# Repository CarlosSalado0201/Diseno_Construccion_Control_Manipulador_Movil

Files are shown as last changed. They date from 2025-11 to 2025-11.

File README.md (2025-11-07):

# 🤖 Diseño, Construcción y Control de un Manipulador Móvil

**Autor:** Carlos Alberto Salado Chávez  
**Institución:** Universidad Tecnológica de la Mixteca – Ingeniería en Mecatrónica  
**Directores:** Dr. Oscar David Ramírez Cárdenas | Dr. Miguel Alberto Domínguez Gurría  
**Fecha:** Noviembre de 2025  

---

## 📘 Descripción general

Este repositorio contiene todo el material correspondiente al proyecto de tesis  
**“Diseño, construcción y control de un manipulador móvil”**, desarrollado en la Universidad Tecnológica de la Mixteca.

El proyecto abarca desde el modelado CAD y la simulación en CoppeliaSim,  
hasta la construcción física del robot y su control cinemático implementado en Arduino.  

El manipulador móvil diseñado utiliza **ruedas omnidireccionales** y un **brazo robótico de 5 grados de libertad**,  
controlado mediante un modelo cinemático combinado que permite posicionar el efector final en el espacio tridimensional.

---

## 🎯 Objetivo general

Diseñar y construir un robot manipulador móvil con ruedas omnidireccionales,  
desarrollando un modelo de control cinemático combinado que coordine los movimientos  
del sistema móvil y del manipulador para alcanzar puntos específicos en el espacio tridimensional.

---

## ⚙️ Estructura del repositorio

```bash
DISENO_CONSTRUCCION_Y_CONTROL_DE_UN_MANIPULADOR_MOVIL/
│
├── CAD_Modelo/                  # Modelado 3D en formato STEP
│   ├── Dibujos_Tecnicos/        # Planos técnicos en PDF
│   └── README_CAD.txt
│
├── Codigo_Arduino/              # Programación del sistema en Arduino
│   ├── Control_Cinematico_Robot_Manipulador_CAOS/
│   ├── mamalon5/
│   └── Lectura_Grafica_monitor_Serial.py
│
├── CoppeliaSim/                 # Simulación del robot en entorno virtual
│
├── Documento/                   # Tesis completa en formato PDF
│
├── PCB_Eagle/                   # Diseño electrónico de la PCB y librerías
│
├── Resultados_Matlab/           # Datos experimentales y scripts de análisis
│
├── VIDEOS/                      # Pruebas experimentales y simulaciones
│
└── README.md                    # Este archivo

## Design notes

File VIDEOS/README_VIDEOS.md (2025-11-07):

# 🎥 VIDEOS – Pruebas y Simulaciones del Manipulador Móvil

Este directorio contiene los **videos experimentales y de simulación** correspondientes a la tesis:

> **“Diseño, construcción y control de un manipulador móvil”**  
> Universidad Tecnológica de la Mixteca  
> Autor: *Carlos Alberto Salado Chávez*  
> Noviembre de 2025

---

## 🧠 Descripción general

Los videos documentan el funcionamiento tanto **virtual (simulado)** como **físico (prototipo real)**  
del robot manipulador móvil omnidireccional desarrollado en el proyecto.  
En cada grabación se muestran distintos aspectos del control cinemático y la coordinación entre la base móvil y el brazo.

---

## 📂 Contenido

| Archivo | Descripción |
|---|---|
| `Primera_simulacion.mp4` | Primera simulación del manipulador móvil en CoppeliaSim (movimiento combinado). |
| `Segunda_simulacion.mp4` | Prueba de control de orientación y posicionamiento del manipulador en simulación. |
| `Tercera_simulacion.mp4` | Simulación completa de seguimiento de trayectoria y orientación del efector final. |
| `Simulacion_manipulador.mp4` | Simulación individual del brazo robótico (cinemática directa e inversa). |
| `Simulacion_Movil.mp4` | Simulación individual del robot móvil omnidireccional. |
| `Primera_prueba.mp4` | Prueba experimental real del robot ensamblado, validando control básico. |
| `Segunda_prueba.mp4` | Prueba de posicionamiento y coordinación entre base móvil y manipulador. |
| `Tercera_prueba.mp4` | Prueba final del sistema completo en entorno controlado. |
| `Representacion_Valores_leidos.mp4` | Visualización de datos de sensores en tiempo real. |
| `Representacion_Valores_leidos_prueba2.mp4` | Segunda prueba de lectura y graficación de variables. |
| `Representacion_Valores_leidos_prueba3.mp4` | Tercera prueba de lectura y graficación de variables. |

---

## ⚙️ Recomendaciones

- Los videos están en formato **.mp4** y pueden abrirse con cualquier reproductor moderno (VLC, Windows Media Player, etc.).  
- Se recomienda **no subirlos directamente a GitHub** si superan los 25 MB;  
  en su lugar, puedes subirlos a **Google Drive, YouTube o GitHub Releases**,  
  y dejar aquí los enlaces de descarga o visualización.

Ejemplo:

```markdown
🔗 [Ver Primera simulación en Google Drive](https://drive.google.com/...)

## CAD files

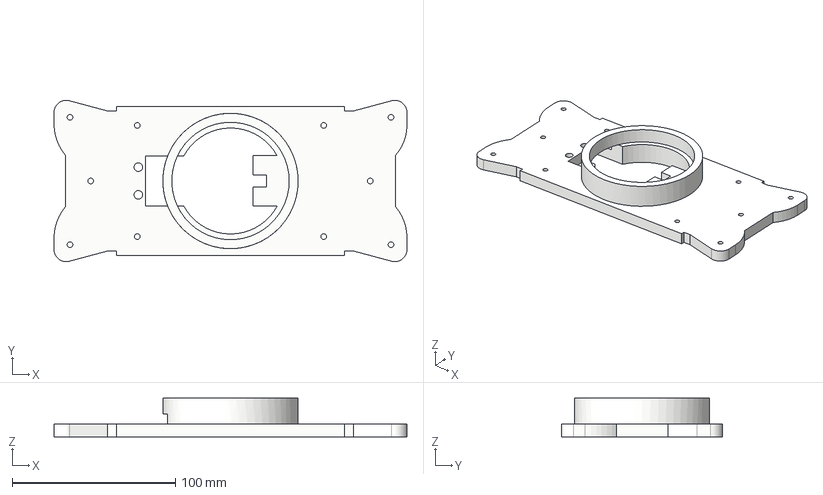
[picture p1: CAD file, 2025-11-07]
CAD_Modelo/tapaa_a_servo_2 v1.step
216.5 x 98.9 x 23.7 mm

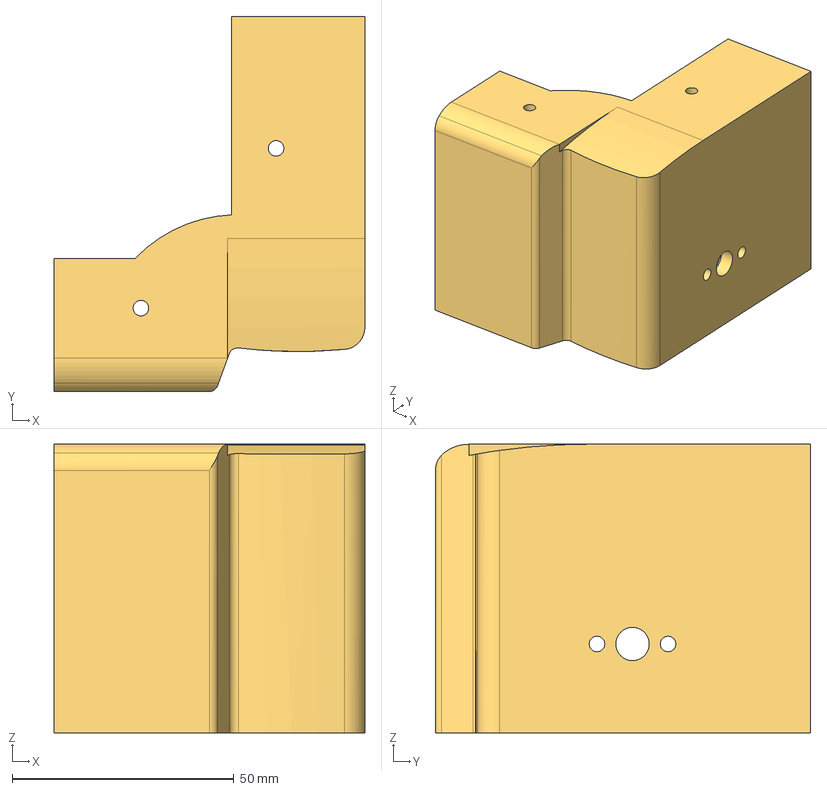
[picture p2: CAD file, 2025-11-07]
CAD_Modelo/Youbot_Componente1_Pieza4 v1.step
70.0 x 84.5 x 65.0 mm

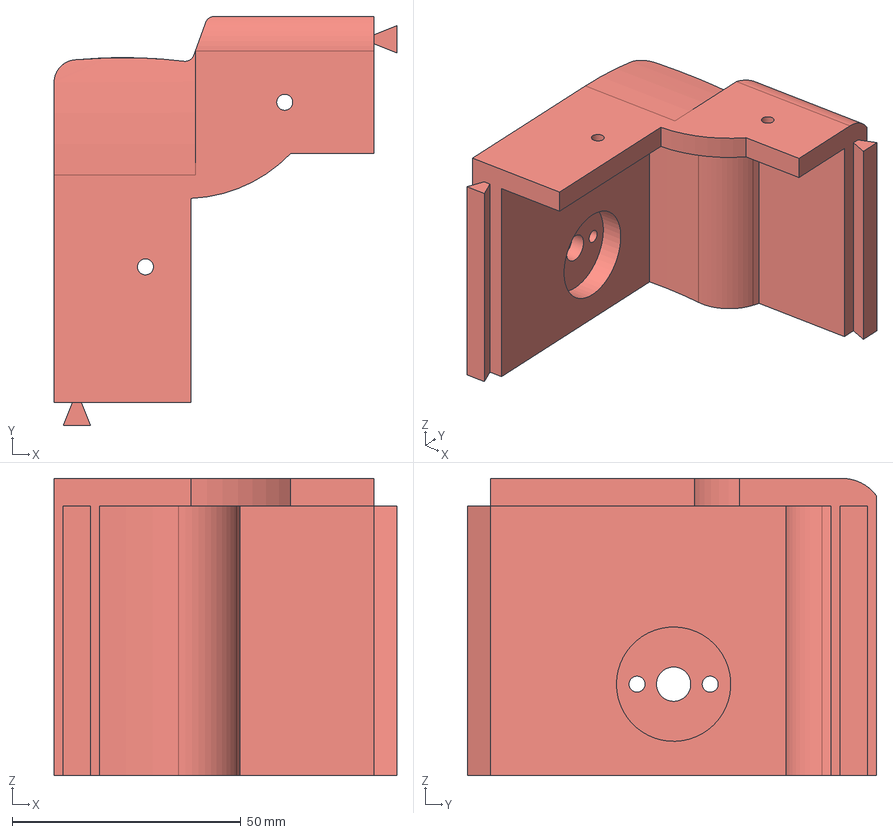
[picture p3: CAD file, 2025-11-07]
CAD_Modelo/Youbot_Componente1_Pieza1 v1.step
75.0 x 89.5 x 65.0 mm

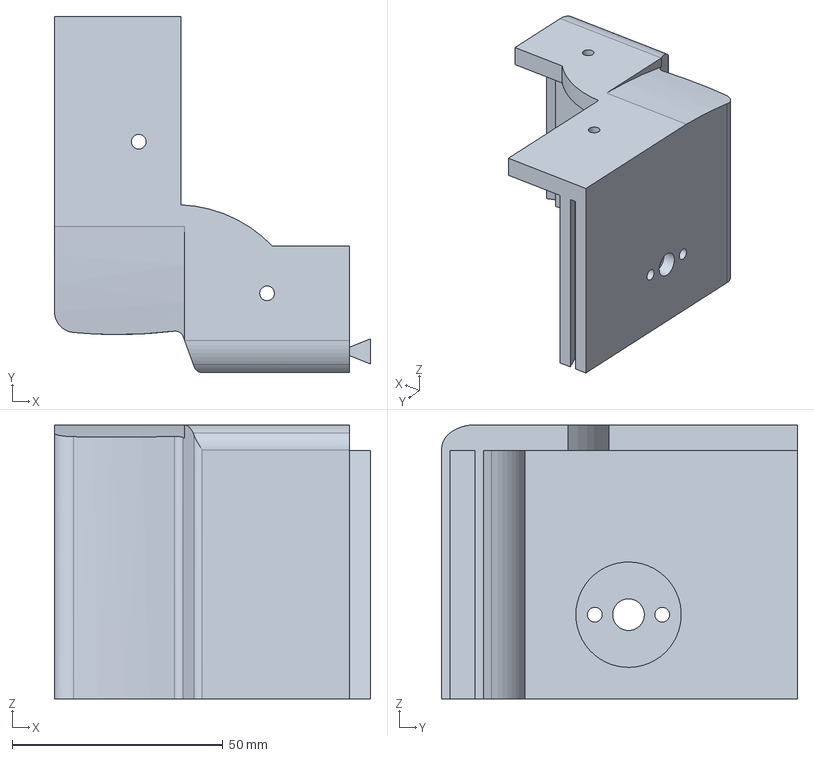
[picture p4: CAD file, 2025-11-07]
CAD_Modelo/Youbot_Componente1_Pieza5 v1.step
75.0 x 84.5 x 65.0 mm

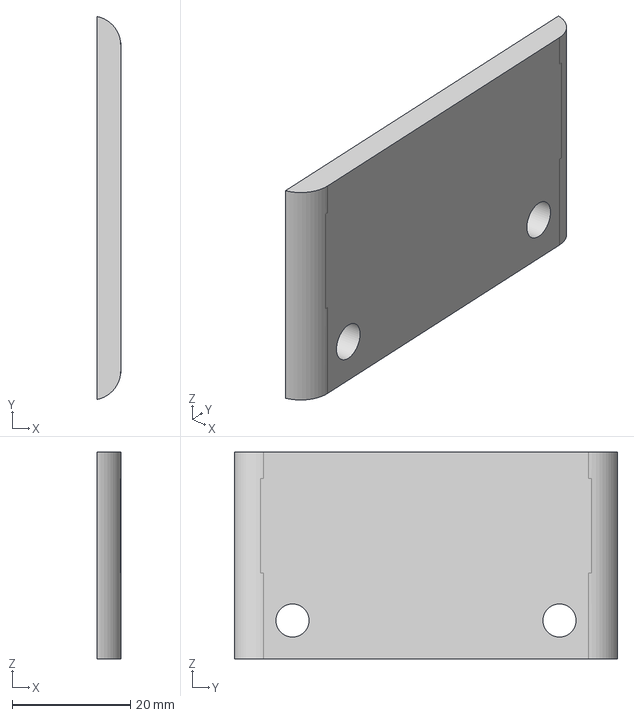
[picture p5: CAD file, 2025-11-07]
CAD_Modelo/tapa_new_gripper v1.step
4.00 x 64.8 x 35.0 mm

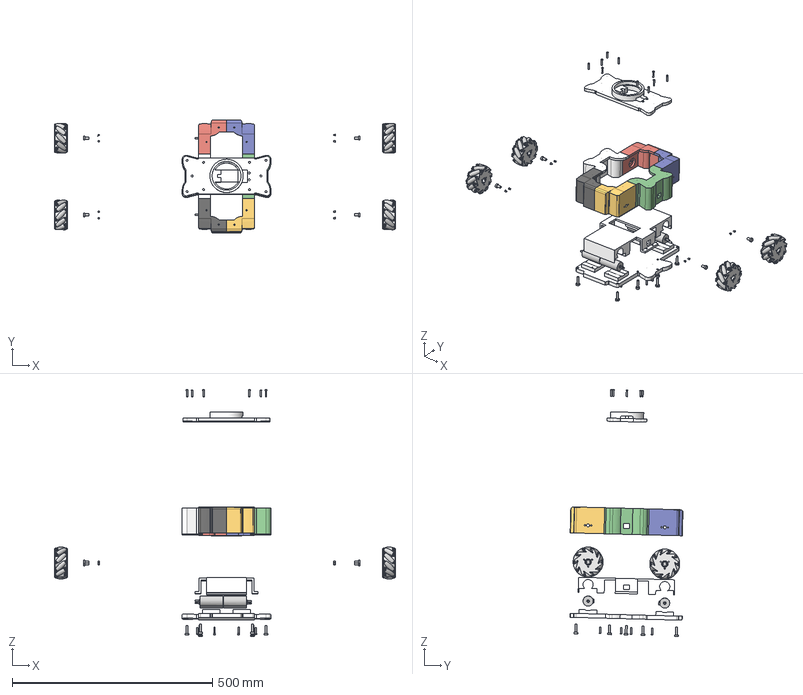
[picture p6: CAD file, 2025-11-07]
CAD_Modelo/MOVIL v1.step
850.7 x 281.8 x 616.3 mm
Youbot_base_corregida v1.step
Youbot_Componente1_Pieza1 v8.step
Youbot_Componente1_Pieza2 v7.step
Youbot_Componente1_Pieza3 v6.step
Youbot_Componente1_Pieza4 v4.step
Youbot_Componente1_Pieza5 v6.step
Youbot_Componente1_Pieza6 v4.step
Labarinto_Motor1 v1.step x 4
arduano_mas_bajito v14.step
tapaa_a_servo_2 v6.step
tornillo3 x 10
Torillo1.75 x 8
Copple x 4
Tornillo1.77x15 x 18
Mecanum wheel 75mm R.STEP_1 x 4
4____________.STEP x 4
1____.STEP x 40
plain washers-s series-grade a gb_GB_FASTENER_WASHER_PWSA 2.STEP x 40
M2________.STEP x 80
2____.STEP x 40
3______.STEP x 80
Mecanum wheel 75mm L.STEP_2 x 4
____.STEP x 40

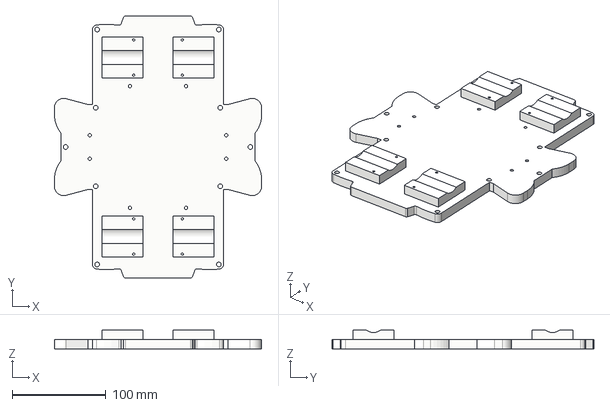
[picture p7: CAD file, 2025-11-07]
CAD_Modelo/Youbot_base_corregida v1.step
221.5 x 280.0 x 20.0 mm

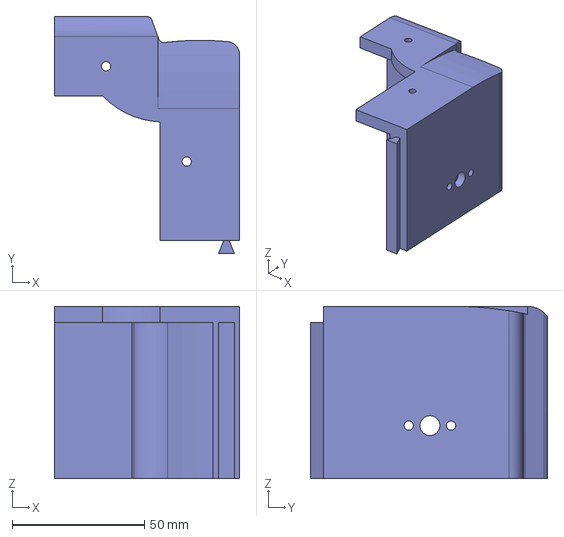
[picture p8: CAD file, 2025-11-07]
CAD_Modelo/Youbot_Componente1_Pieza2 v1.step
70.0 x 89.5 x 65.0 mm

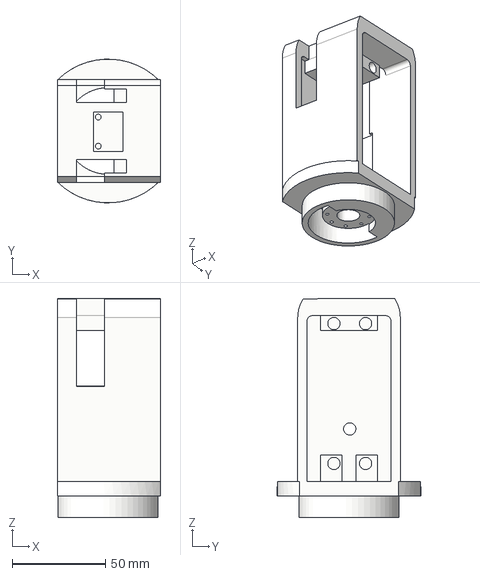
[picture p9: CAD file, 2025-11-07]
CAD_Modelo/Eslabon_Giro__Bien v1.step
55.0 x 77.0 x 117.5 mm

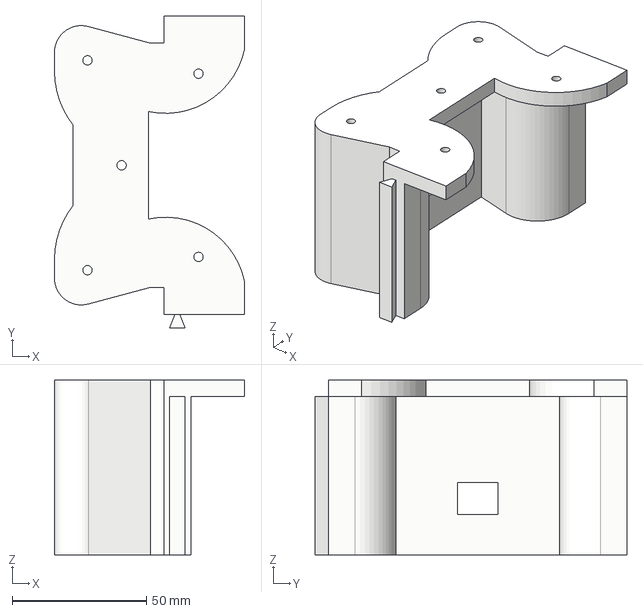
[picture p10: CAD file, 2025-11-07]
CAD_Modelo/Youbot_Componente1_Pieza6 v1.step
70.7 x 116.1 x 65.0 mm

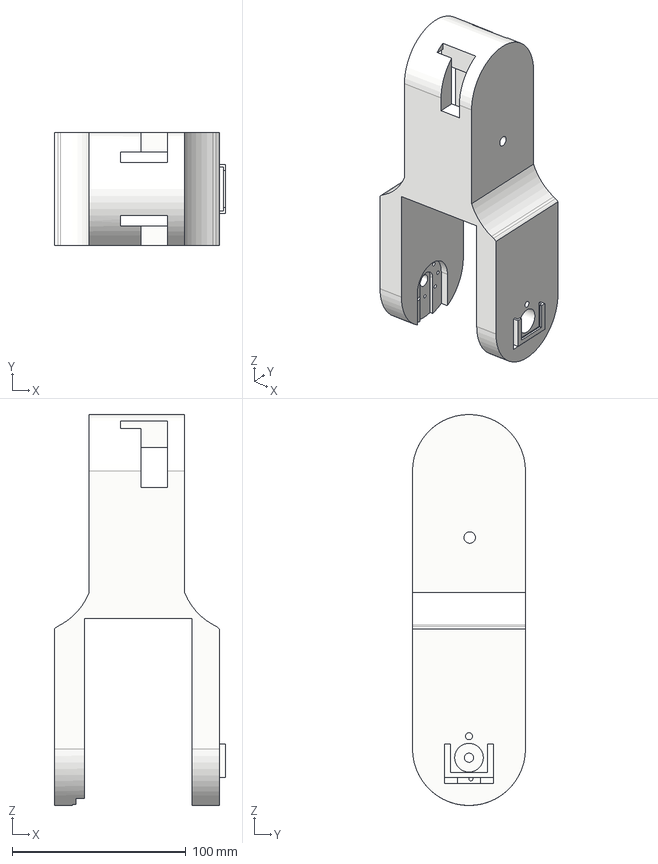
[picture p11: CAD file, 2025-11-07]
CAD_Modelo/Eslabon2_de_cero v1.step
98.6 x 65.0 x 225.0 mm

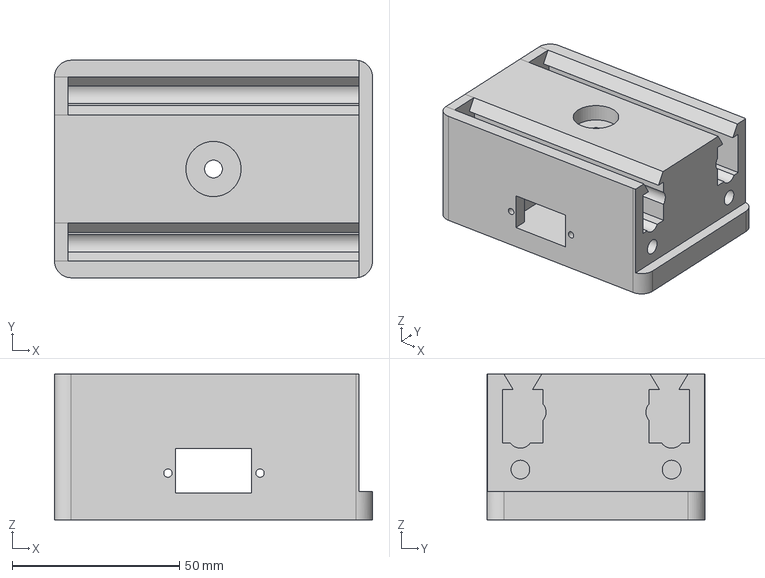
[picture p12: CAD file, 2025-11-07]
CAD_Modelo/new_gripper v1.step
95.0 x 65.0 x 43.5 mm

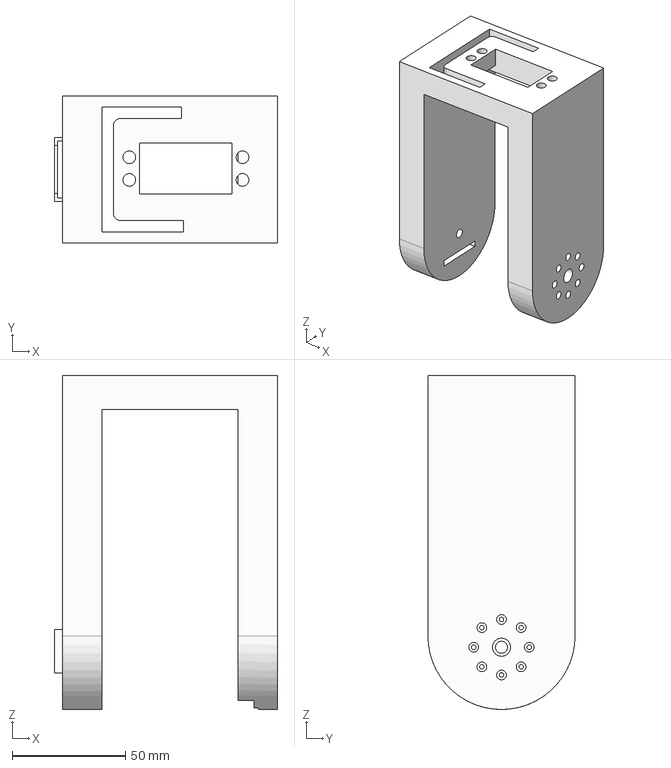
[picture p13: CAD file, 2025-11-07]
CAD_Modelo/Eslabon3 v1.step
98.6 x 65.0 x 147.5 mm

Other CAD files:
CAD_Modelo/Youbot_Componente1_Pieza3 v1.step

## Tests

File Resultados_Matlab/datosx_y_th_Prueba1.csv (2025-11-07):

sampleTime | x | y | th | th1 | th2 | th3 | th4 | th5 | th1m | th2m | th3m | th4m | th5m
1 | -0.01 | 0 | 0 | 0 | 0 | 0 | 0 | 0 | 0 | 0 | 0 | 0 | 0
2 | 0 | 0 | 0 | 0 | -1.42 | 0 | 1.42 | 0 | 0 | -1.42 | -6.28 | 1.42 | 0
3 | 0.01 | 0 | -0.01 | 0 | -1.42 | 0 | 1.42 | 0 | 0 | -1.42 | -6.28 | 1.42 | 0
4 | 0.02 | 0 | -0.01 | 0.01 | -1.41 | 0 | 1.41 | 0 | 0.01 | -1.41 | -6.28 | 1.41 | -0.01
5 | 0.02 | 0 | -0.02 | 0.01 | -1.41 | 0 | 1.41 | 0 | 0.01 | -1.41 | -6.28 | 1.41 | -0.01
6 | 0.03 | 0 | -0.02 | 0.02 | -1.41 | 0 | 1.41 | 0 | 0.02 | -1.41 | -6.28 | 1.41 | -0.02
7 | 0.04 | 0 | -0.03 | 0.02 | -1.41 | 0 | 1.41 | 0 | 0.02 | -1.41 | -6.28 | 1.41 | -0.03
8 | 0.05 | 0 | -0.03 | 0.03 | -1.41 | 0 | 1.41 | 0 | 0.03 | -1.41 | -6.28 | 1.41 | -0.03
9 | 0.06 | 0 | -0.04 | 0.04 | -1.41 | 0 | 1.41 | 0 | 0.04 | -1.41 | -6.28 | 1.41 | -0.04
10 | 0.07 | 0 | -0.05 | 0.04 | -1.41 | 0 | 1.41 | 0 | 0.04 | -1.41 | -6.28 | 1.41 | -0.04
11 | 0.08 | 0 | -0.05 | 0.05 | -1.41 | 0 | 1.41 | 0 | 0.05 | -1.41 | -6.28 | 1.41 | -0.05
12 | 0.08 | 0 | -0.06 | 0.06 | -1.4 | 0 | 1.4 | 0 | 0.06 | -1.4 | -6.28 | 1.4 | -0.06
13 | 0.09 | 0 | -0.07 | 0.07 | -1.4 | 0 | 1.4 | -0.01 | 0.07 | -1.4 | -6.28 | 1.4 | -0.07
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

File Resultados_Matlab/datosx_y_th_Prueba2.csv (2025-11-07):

sampleTime | x | y | th | th1 | th2 | th3 | th4 | th5 | th1m | th2m | th3m | th4m | th5m
1 | -0.62 | -0.01 | 0 | 0 | 0 | 0 | 0 | 0 | 0 | 0 | 0 | 0 | 0
2 | 0 | 0 | -0.01 | -1.57 | -1.51 | -6.28 | 0.73 | 1.57 | -1.57 | -1.51 | -6.28 | 0.73 | 1.57
3 | -0.01 | -0.01 | -0.03 | -1.57 | -1.51 | -6.28 | 0.73 | 1.57 | -1.57 | -1.51 | -6.28 | 0.73 | 1.57
4 | -0.01 | -0.01 | -0.04 | -1.57 | -1.51 | -6.28 | 0.73 | 1.57 | -1.57 | -1.51 | -6.28 | 0.73 | 1.57
5 | -0.02 | -0.02 | -0.04 | -1.57 | -1.51 | -6.28 | 0.73 | 1.57 | -1.57 | -1.51 | -6.28 | 0.73 | 1.57
6 | -0.03 | -0.02 | -0.04 | -1.57 | -1.51 | -6.28 | 0.73 | 1.57 | -1.57 | -1.51 | -6.28 | 0.73 | 1.57
7 | -0.03 | -0.03 | -0.05 | -1.57 | -1.51 | -6.28 | 0.73 | 1.57 | -1.57 | -1.51 | -6.28 | 0.73 | 1.57
8 | -0.04 | -0.03 | -0.05 | -1.57 | -1.51 | -6.28 | 0.73 | 1.57 | -1.57 | -1.51 | -6.28 | 0.73 | 1.57
9 | -0.05 | -0.04 | -0.05 | -1.57 | -1.51 | -6.28 | 0.73 | 1.57 | -1.57 | -1.51 | -6.28 | 0.73 | 1.57
10 | -0.06 | -0.04 | -0.06 | -1.57 | -1.51 | -6.28 | 0.73 | 1.57 | -1.57 | -1.51 | -6.28 | 0.73 | 1.57
11 | -0.07 | -0.05 | -0.05 | -1.57 | -1.51 | -6.28 | 0.73 | 1.57 | -1.57 | -1.51 | -6.28 | 0.73 | 1.57
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

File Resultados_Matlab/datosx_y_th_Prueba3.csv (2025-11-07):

sampleTime | x | y | th | th1 | th2 | th3 | th4 | th5
1 | -0.99 | 0.53 | 0 | 0 | 0 | 0 | 0 | 0
2 | 0 | 0 | 0 | -1.52 | -1.37 | -6.28 | 0.89 | 1.57
3 | 0 | -0.01 | -0.01 | -1.52 | -1.37 | -6.28 | 0.89 | 1.57
4 | 0 | -0.01 | -0.01 | -1.51 | -1.37 | -6.28 | 0.89 | 1.57
5 | 0.01 | -0.02 | -0.01 | -1.52 | -1.37 | -6.28 | 0.89 | 1.57
6 | 0.01 | -0.02 | -0.01 | -1.52 | -1.37 | -6.28 | 0.89 | 1.57
7 | 0.01 | -0.03 | -0.01 | -1.52 | -1.37 | -6.28 | 0.89 | 1.57
8 | 0.01 | -0.03 | -0.01 | -1.52 | -1.36 | -6.28 | 0.89 | 1.57
9 | 0.01 | -0.04 | -0.02 | -1.52 | -1.36 | -6.28 | 0.89 | 1.57
10 | 0.02 | -0.05 | -0.02 | -1.52 | -1.36 | -6.28 | 0.88 | 1.57
11 | 0.02 | -0.05 | -0.02 | -1.52 | -1.36 | -6.28 | 0.88 | 1.57
12 | 0.02 | -0.06 | -0.01 | -1.51 | -1.36 | -6.28 | 0.88 | 1.57
13 | 0.02 | -0.07 | 0 | -1.52 | -1.36 | -6.28 | 0.88 | 1.57
14 | 0.02 | -0.08 | 0.01 | -1.54 | -1.35 | -6.28 | 0.87 | 1.57
15 | 0.02 | -0.09 | 0.01 | -1.54 | -1.35 | -6.28 | 0.87 | 1.57
16 | 0.02 | -0.1 | 0.01 | -1.55 | -1.35 | -6.28 | 0.86 | 1.57
17 | 0.02 | -0.1 | 0.01 | -1.55 | -1.35 | -6.28 | 0.86 | 1.57
18 | 0.02 | -0.11 | 0.02 | -1.56 | -1.35 | -6.28 | 0.86 | 1.57
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

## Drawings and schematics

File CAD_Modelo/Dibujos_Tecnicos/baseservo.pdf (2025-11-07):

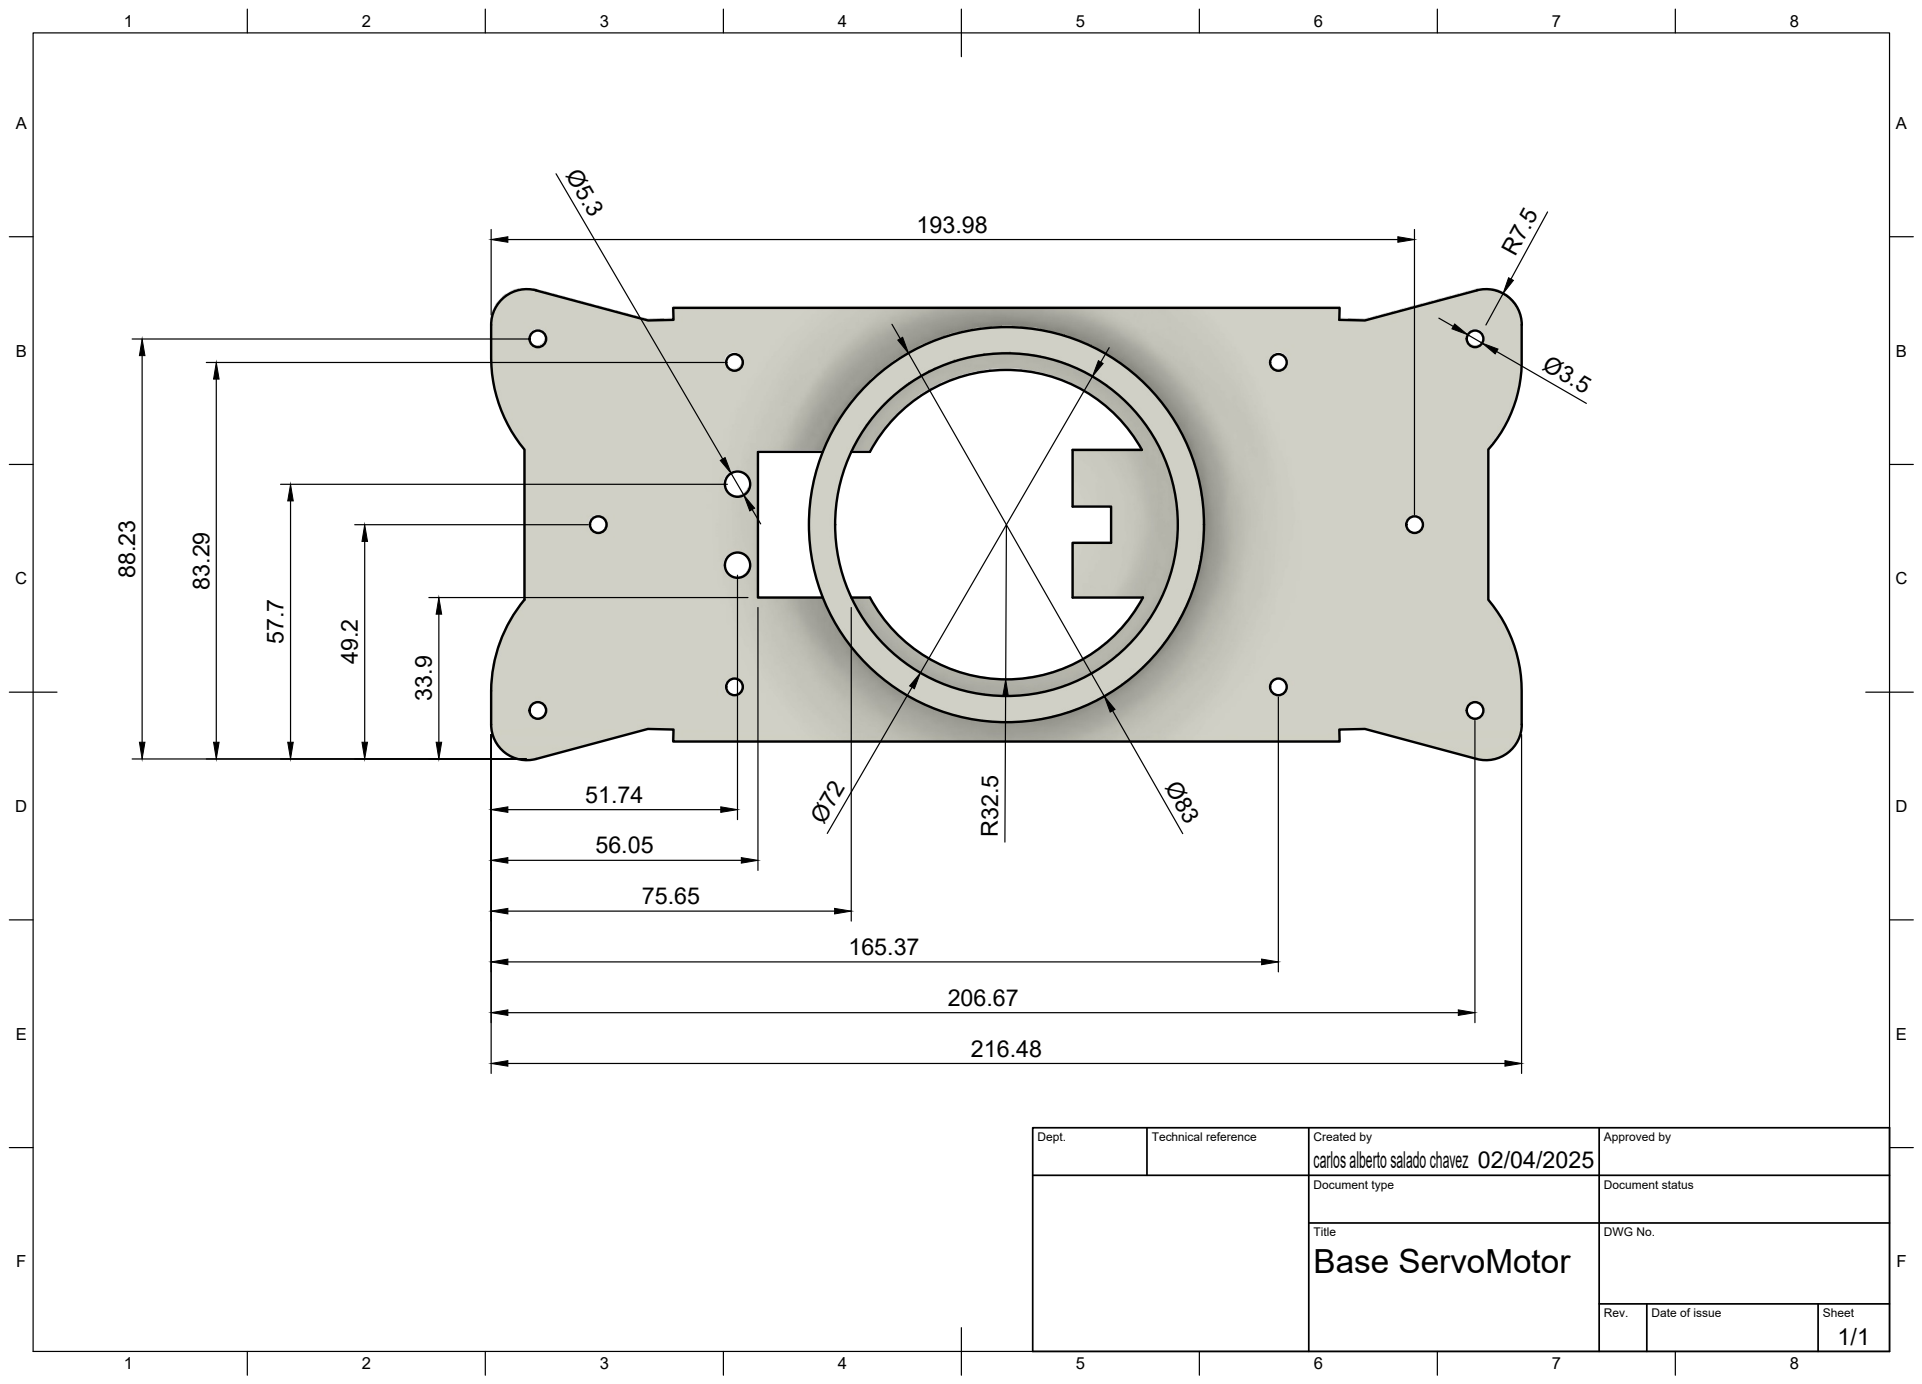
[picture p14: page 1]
Title; DWG No.; Rev.; Date of issue; Sheet; Base ServoMotor

Dept. | Technical reference | Created by carlos alberto salado chavez 02/04/2025 | Approved by

Document type | Document status

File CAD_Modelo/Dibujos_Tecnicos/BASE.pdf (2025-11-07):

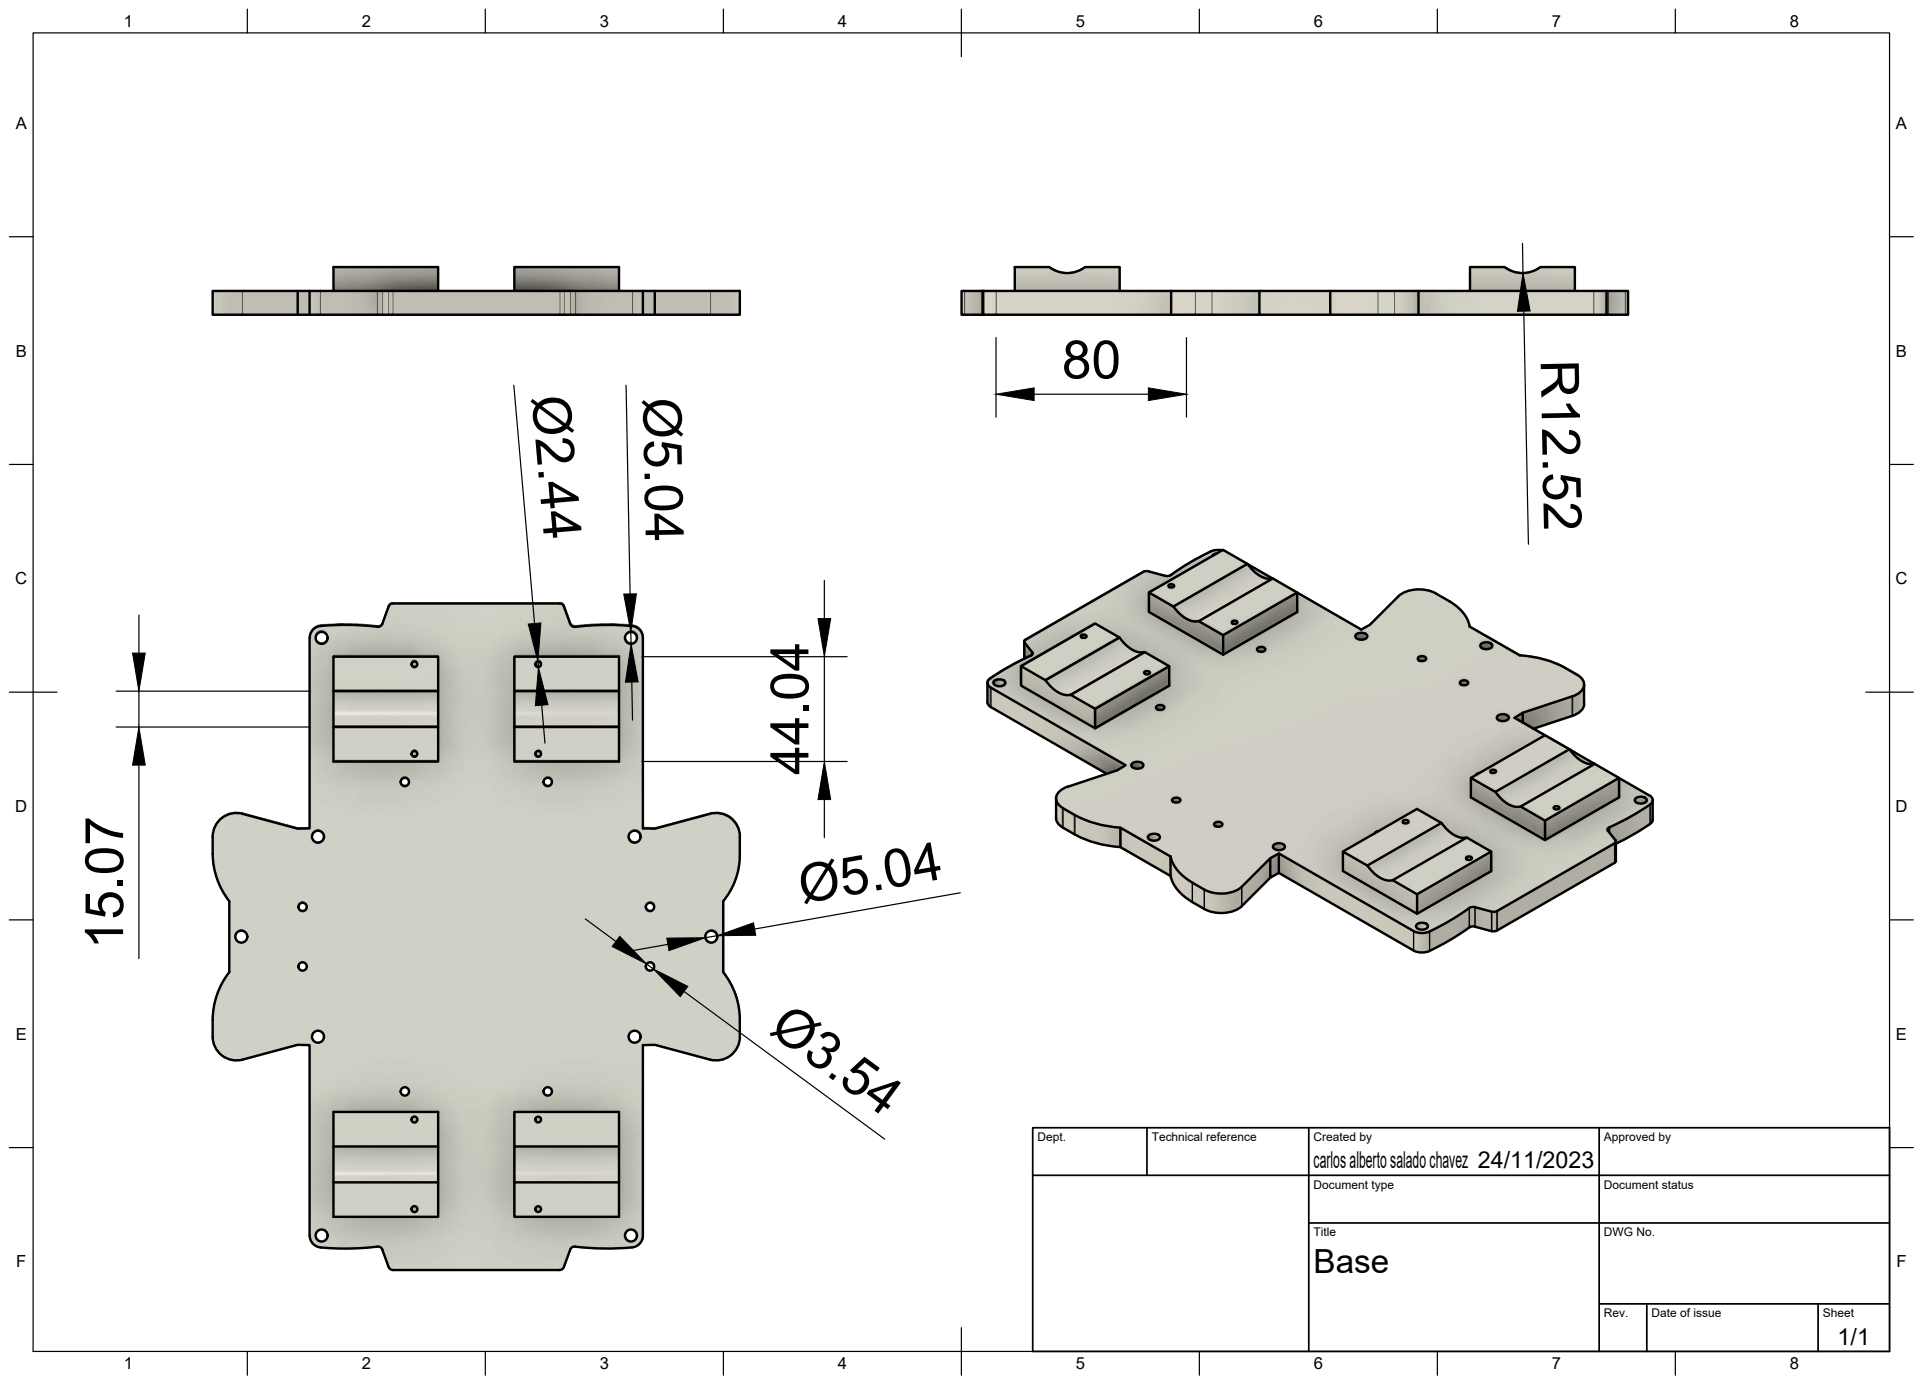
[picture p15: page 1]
8 BCDEF; ABCDEF; Title; DWG No.; Rev.; Date of issue; Sheet; carlos alberto salado chavez Ø5.04

Dept. | Technical reference | Created by 24/11/2023 | Approved by

Document type | Document status

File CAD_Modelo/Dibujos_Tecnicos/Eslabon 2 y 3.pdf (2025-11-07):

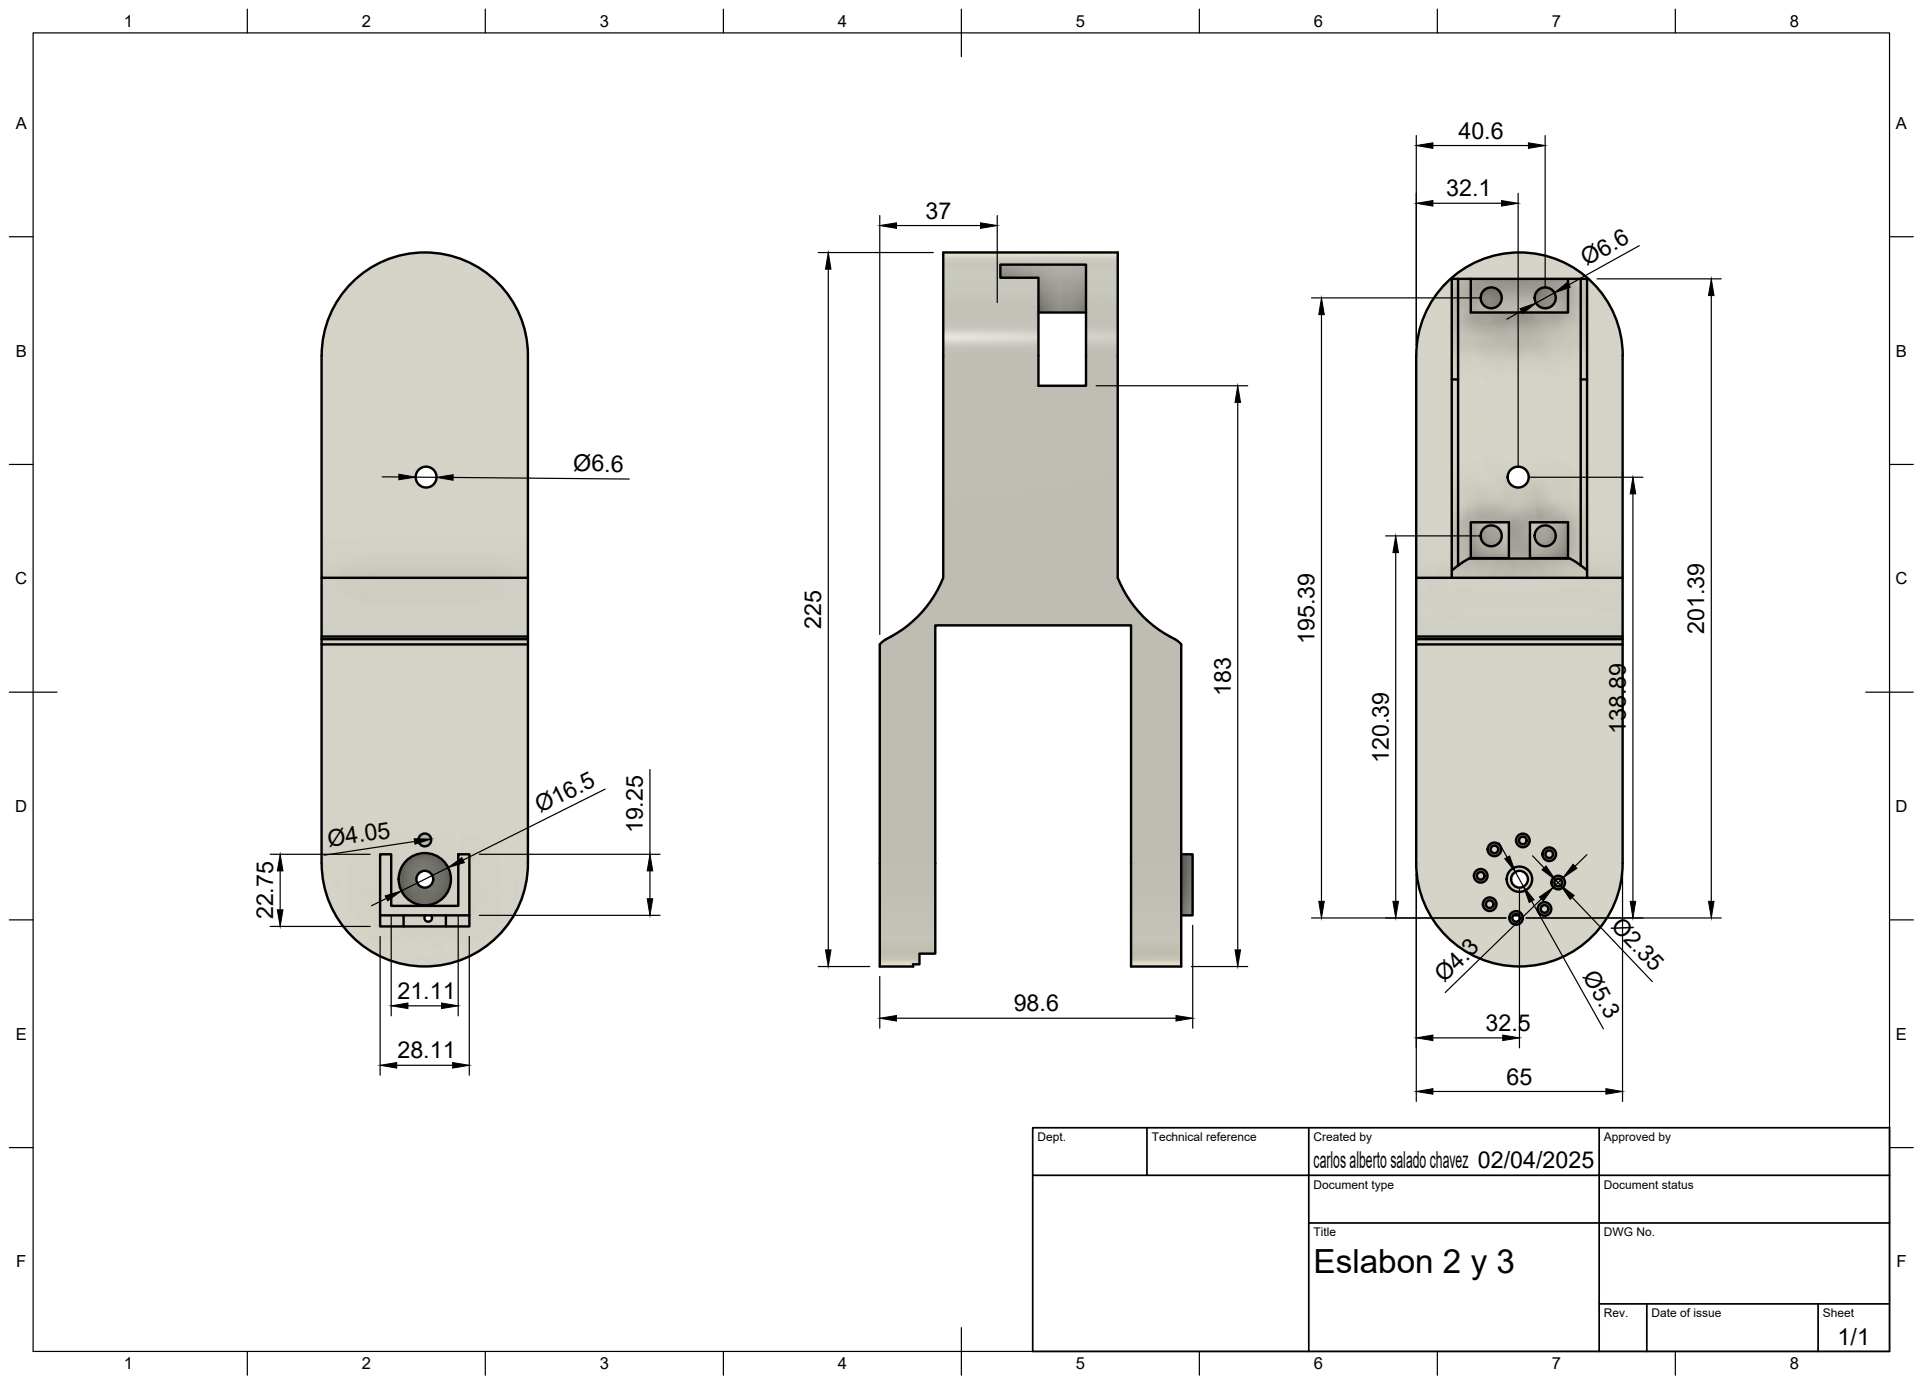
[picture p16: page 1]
8 BCDEF; ABCDEF; Title; DWG No.; Rev.; Date of issue; Sheet; Eslabon 2 y 3

Dept. | Technical reference | Created by carlos alberto salado chavez 02/04/2025 | Approved by

Document type | Document status

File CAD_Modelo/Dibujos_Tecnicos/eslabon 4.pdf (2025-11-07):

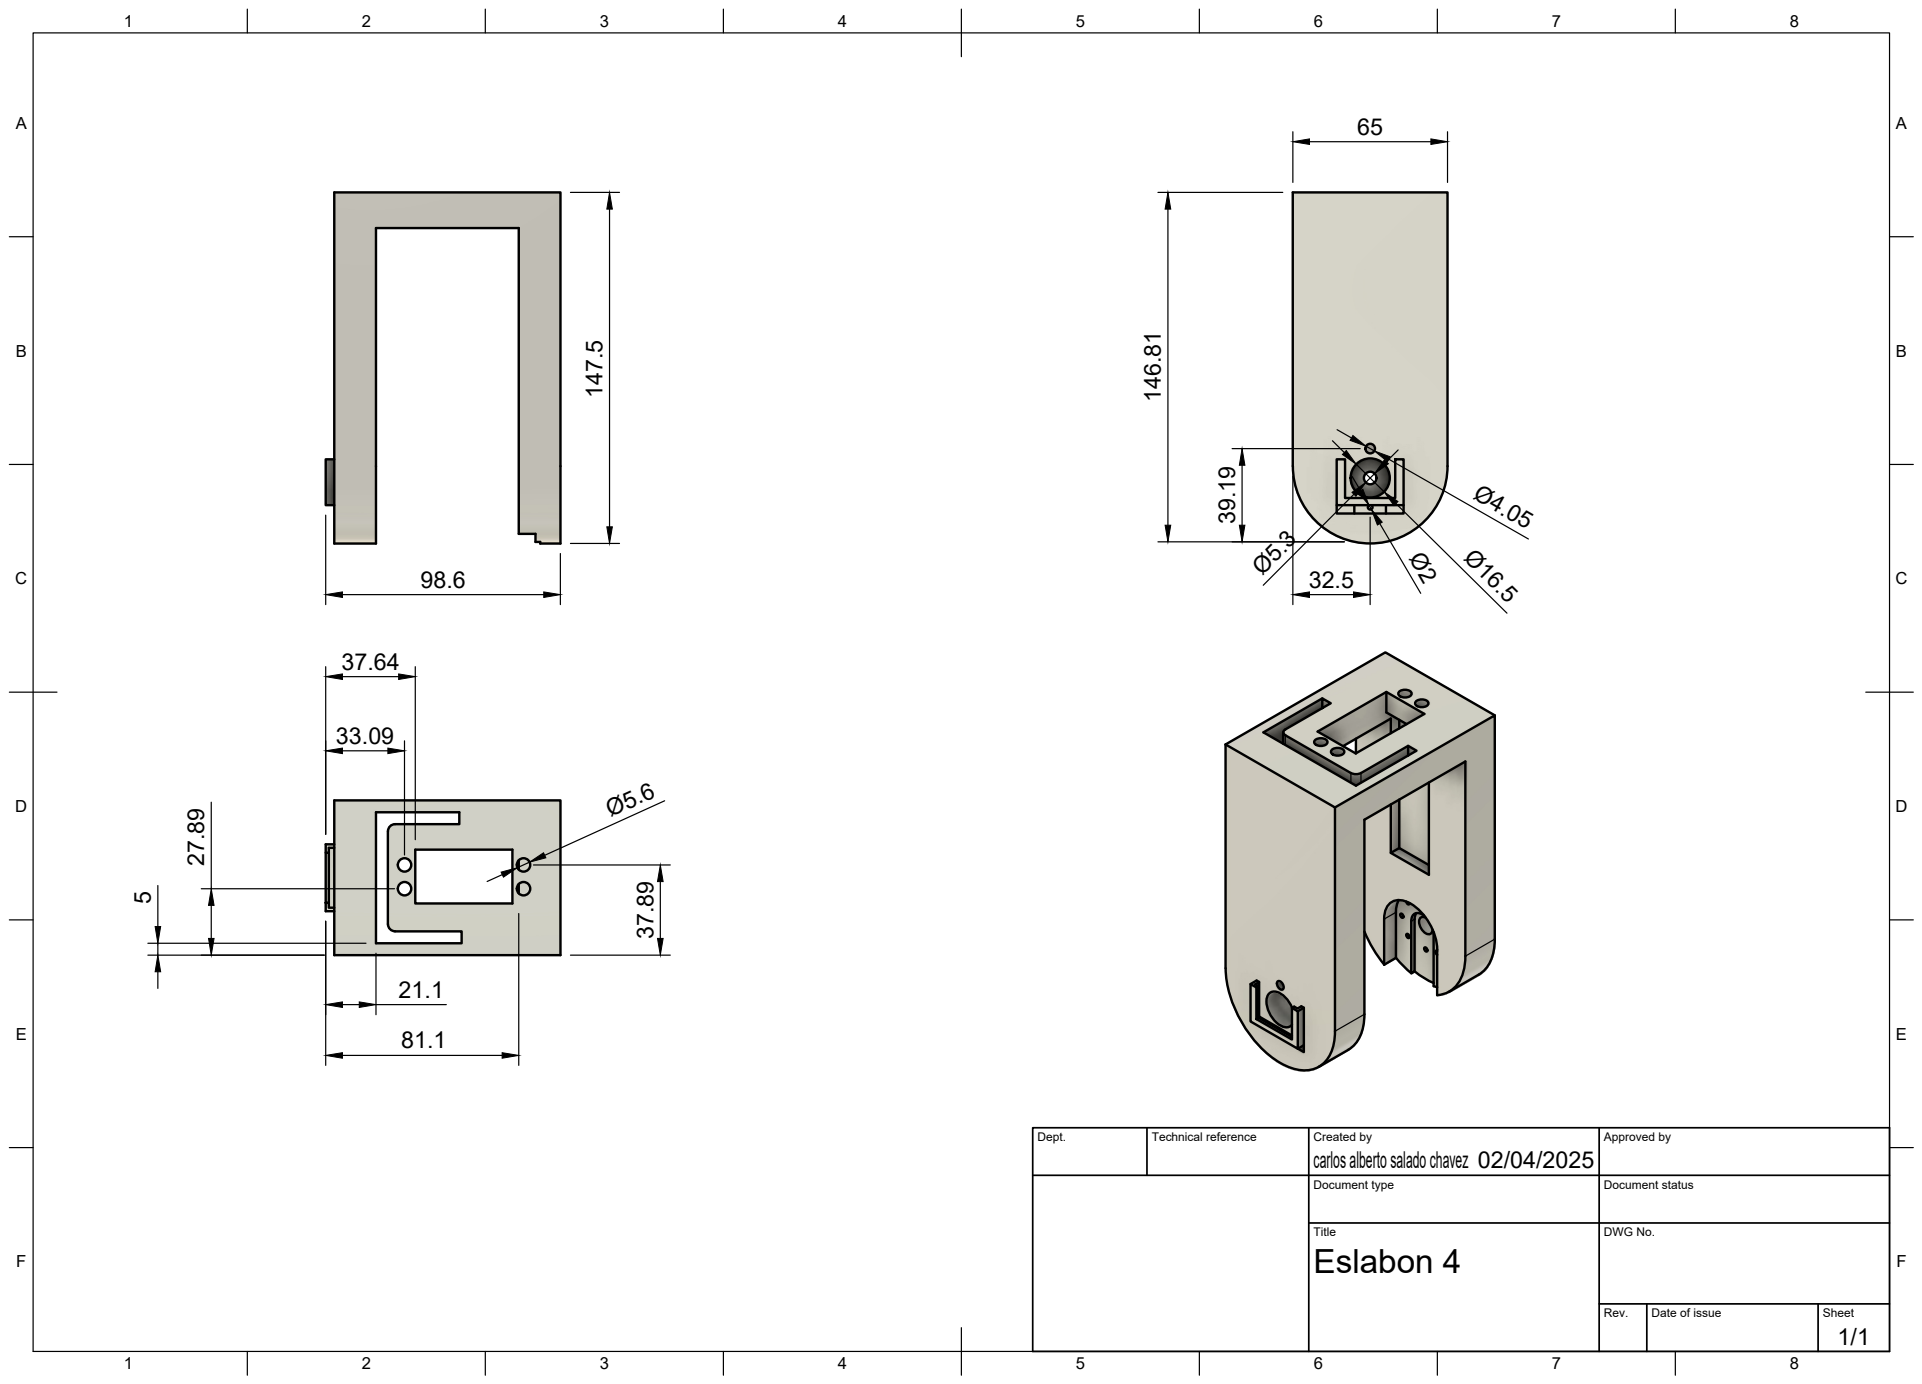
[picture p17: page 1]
Title; DWG No.; Rev.; Date of issue; Sheet; Eslabon 4

carlos alberto salado chavez 147.5

Dept. | Technical reference | Created by 02/04/2025 | Approved by

Document type | Document status

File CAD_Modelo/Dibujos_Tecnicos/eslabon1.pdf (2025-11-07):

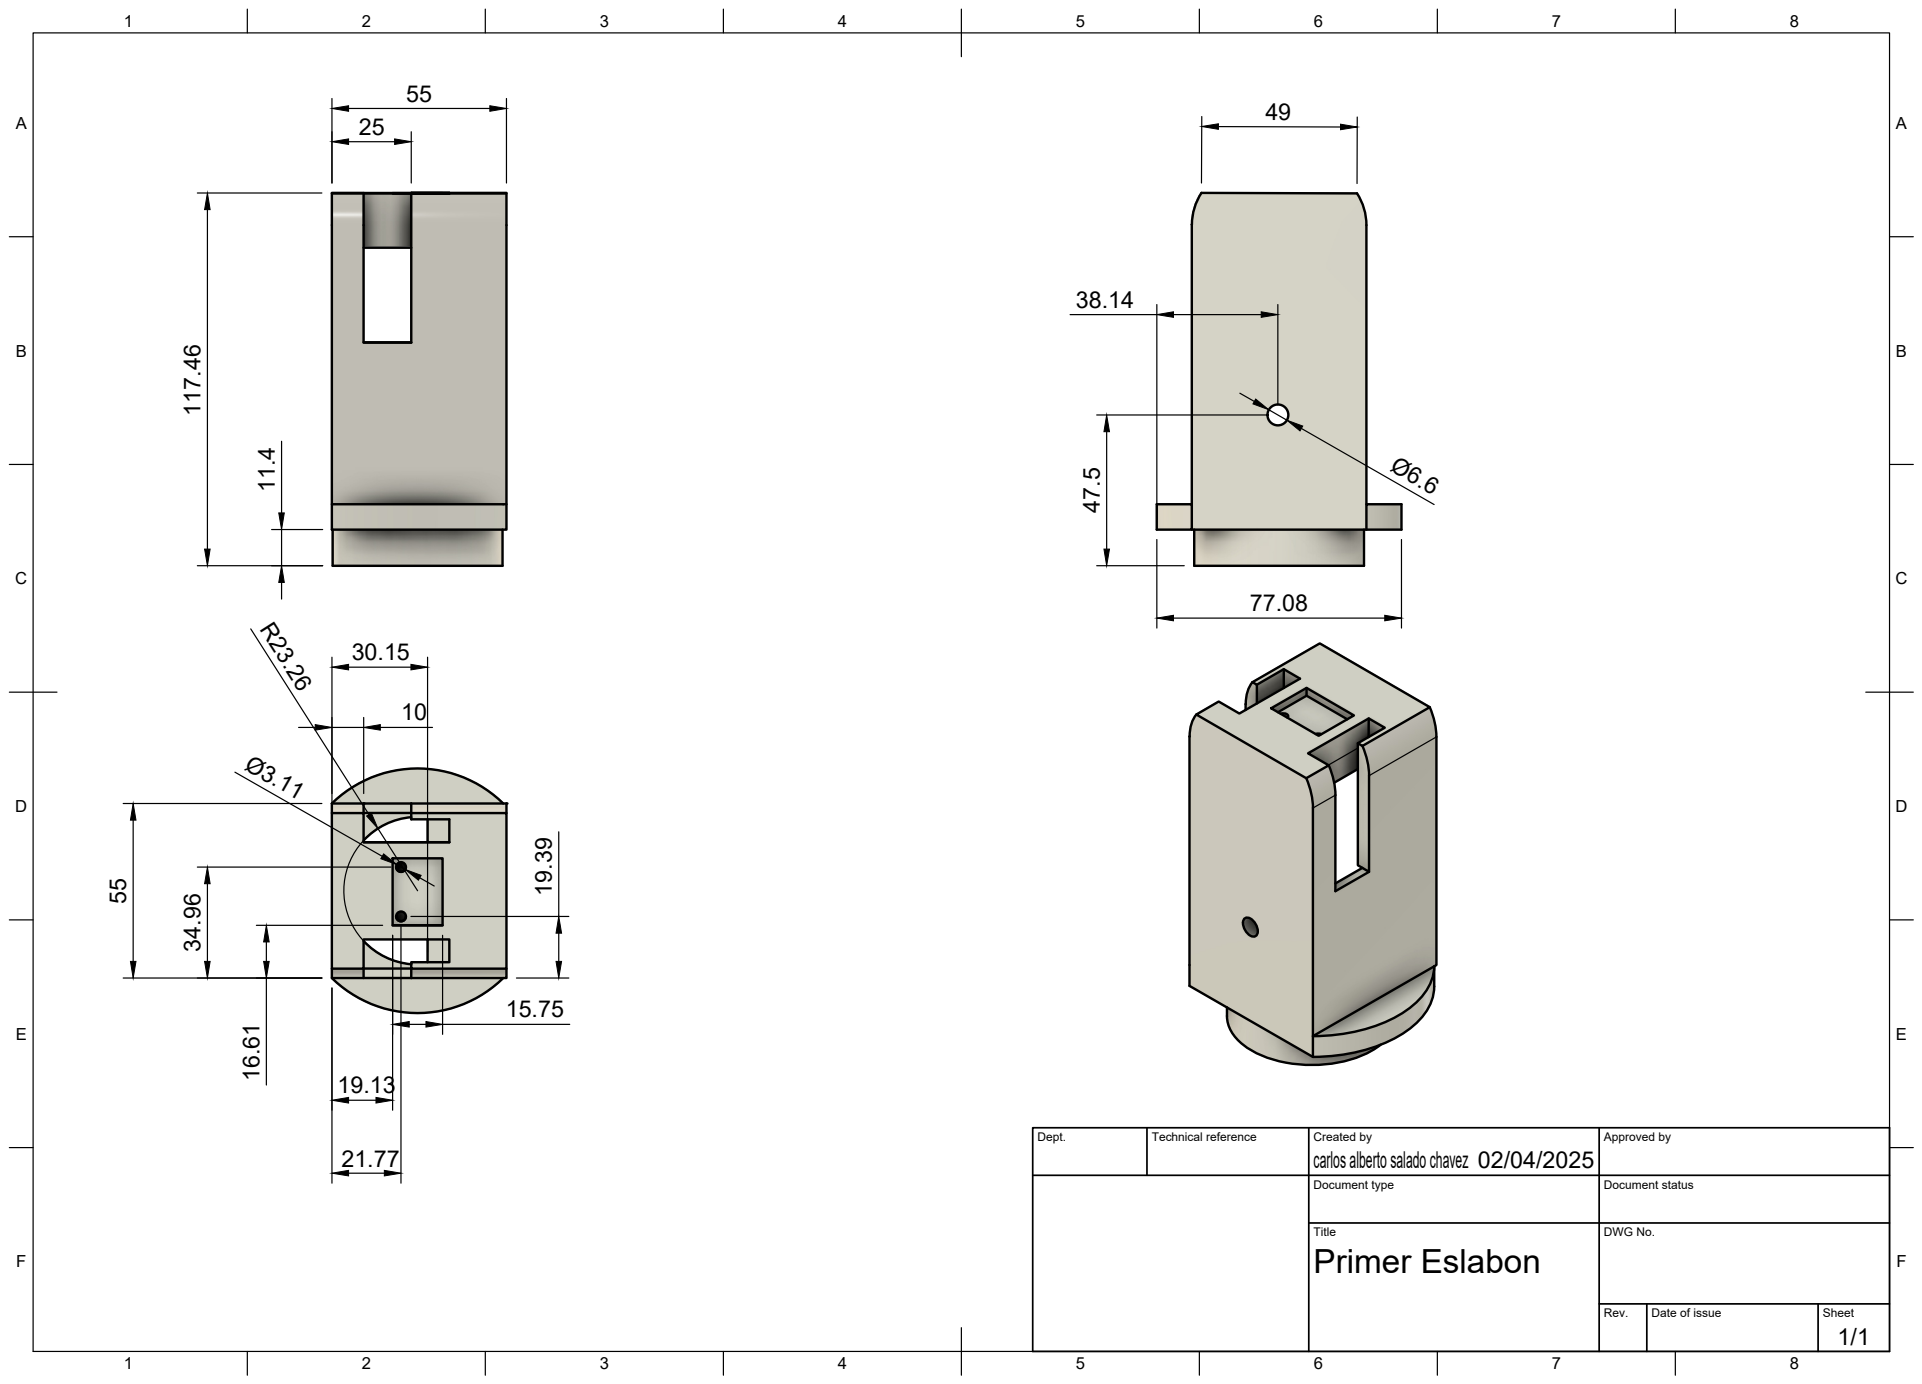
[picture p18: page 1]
Title; DWG No.; Rev.; Date of issue; Sheet; Primer Eslabon

Dept. | Technical reference | Created by carlos alberto salado chavez 02/04/2025 | Approved by

Document type | Document status

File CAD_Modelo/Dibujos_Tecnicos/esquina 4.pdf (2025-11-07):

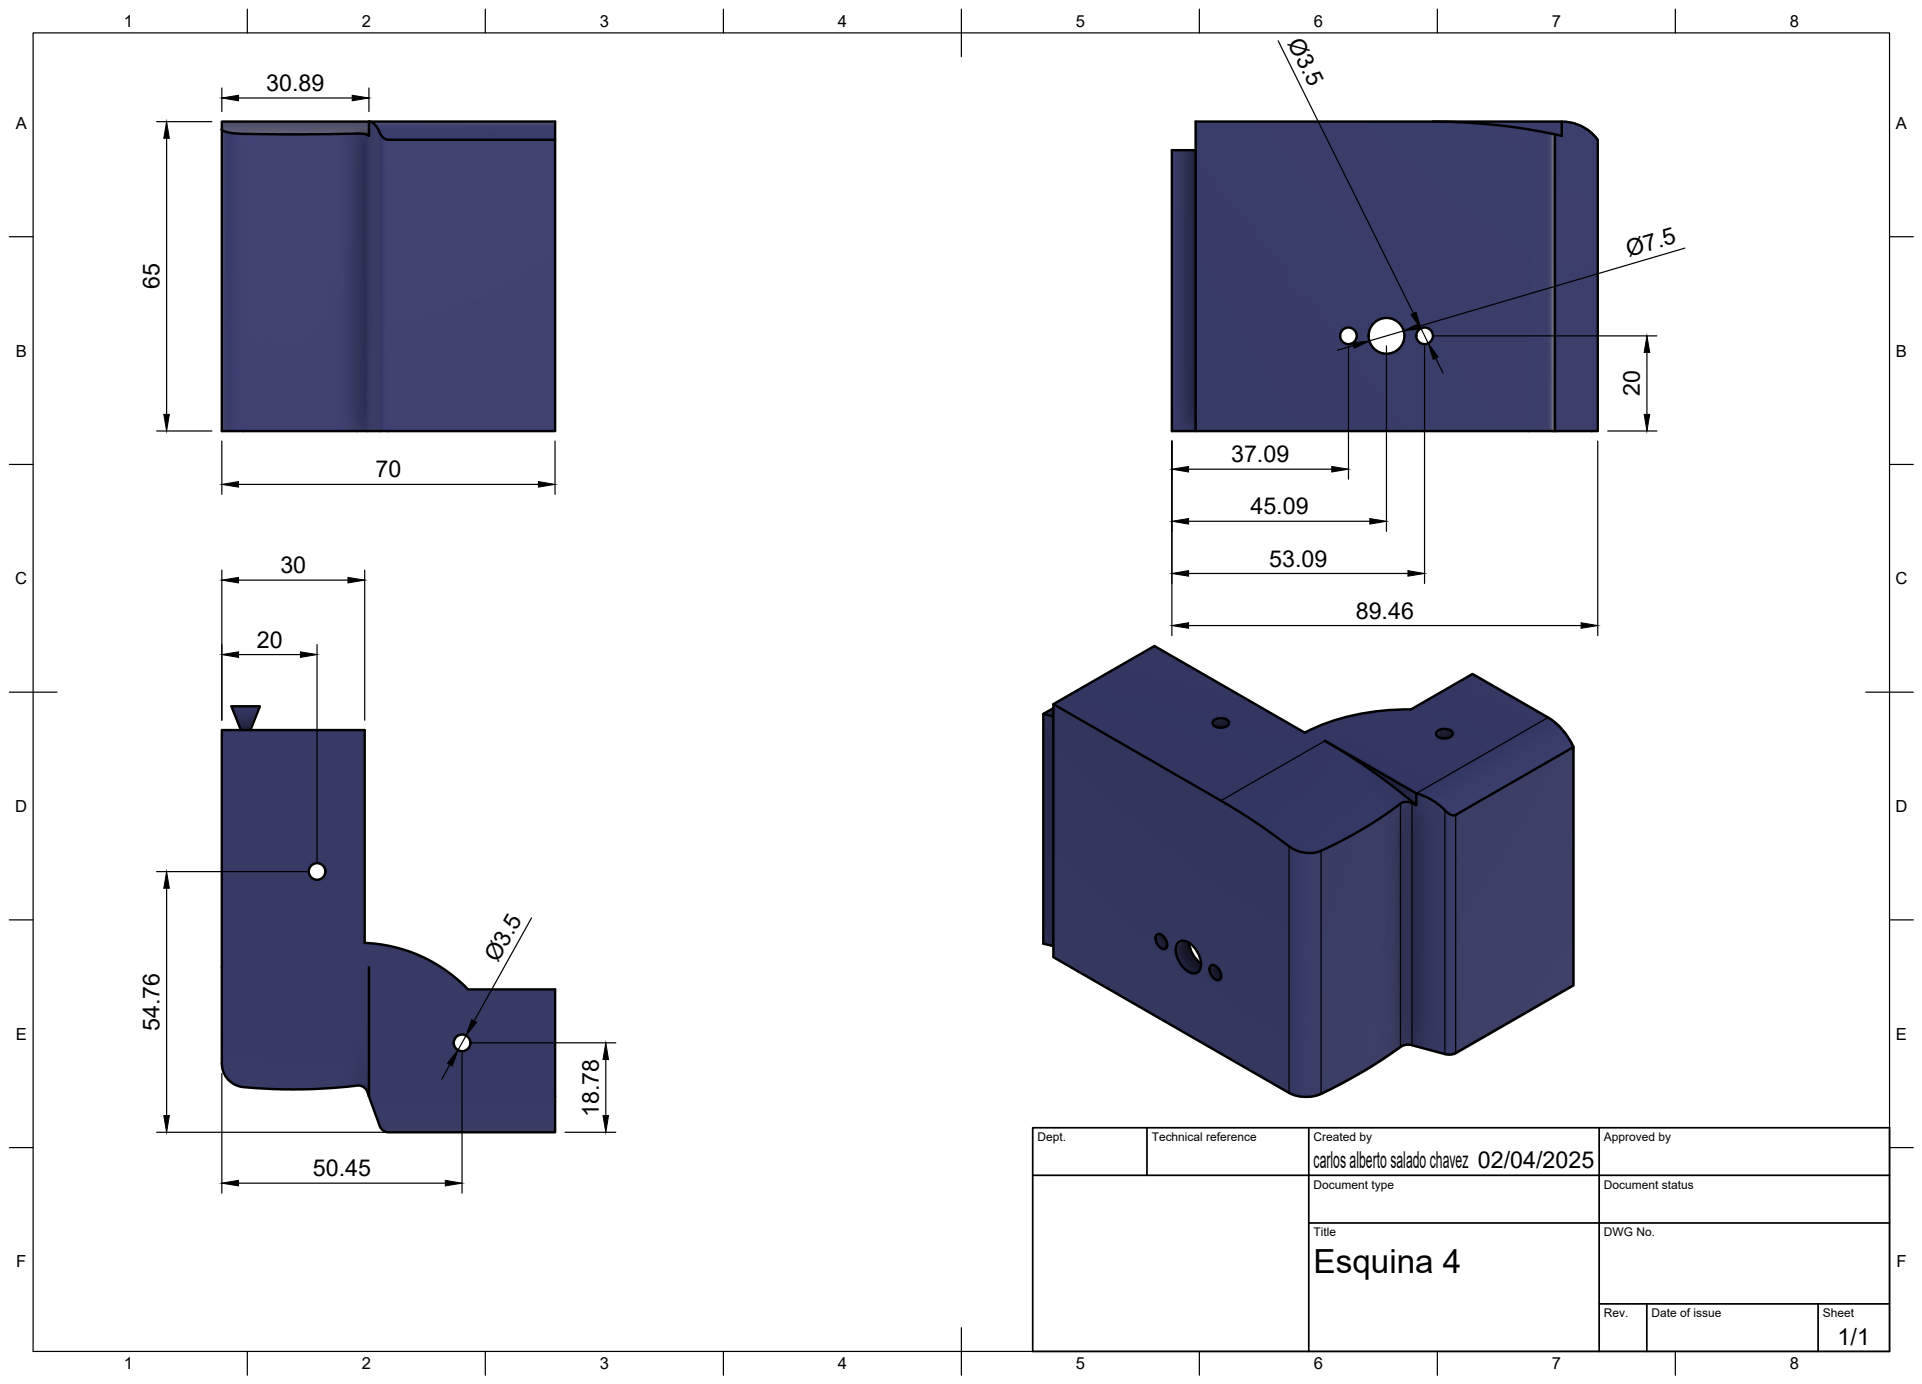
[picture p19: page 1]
Title; DWG No.; Rev.; Date of issue; Sheet; Esquina 4

Dept. | Technical reference | Created by carlos alberto salado chavez 02/04/2025 | Approved by

Document type | Document status

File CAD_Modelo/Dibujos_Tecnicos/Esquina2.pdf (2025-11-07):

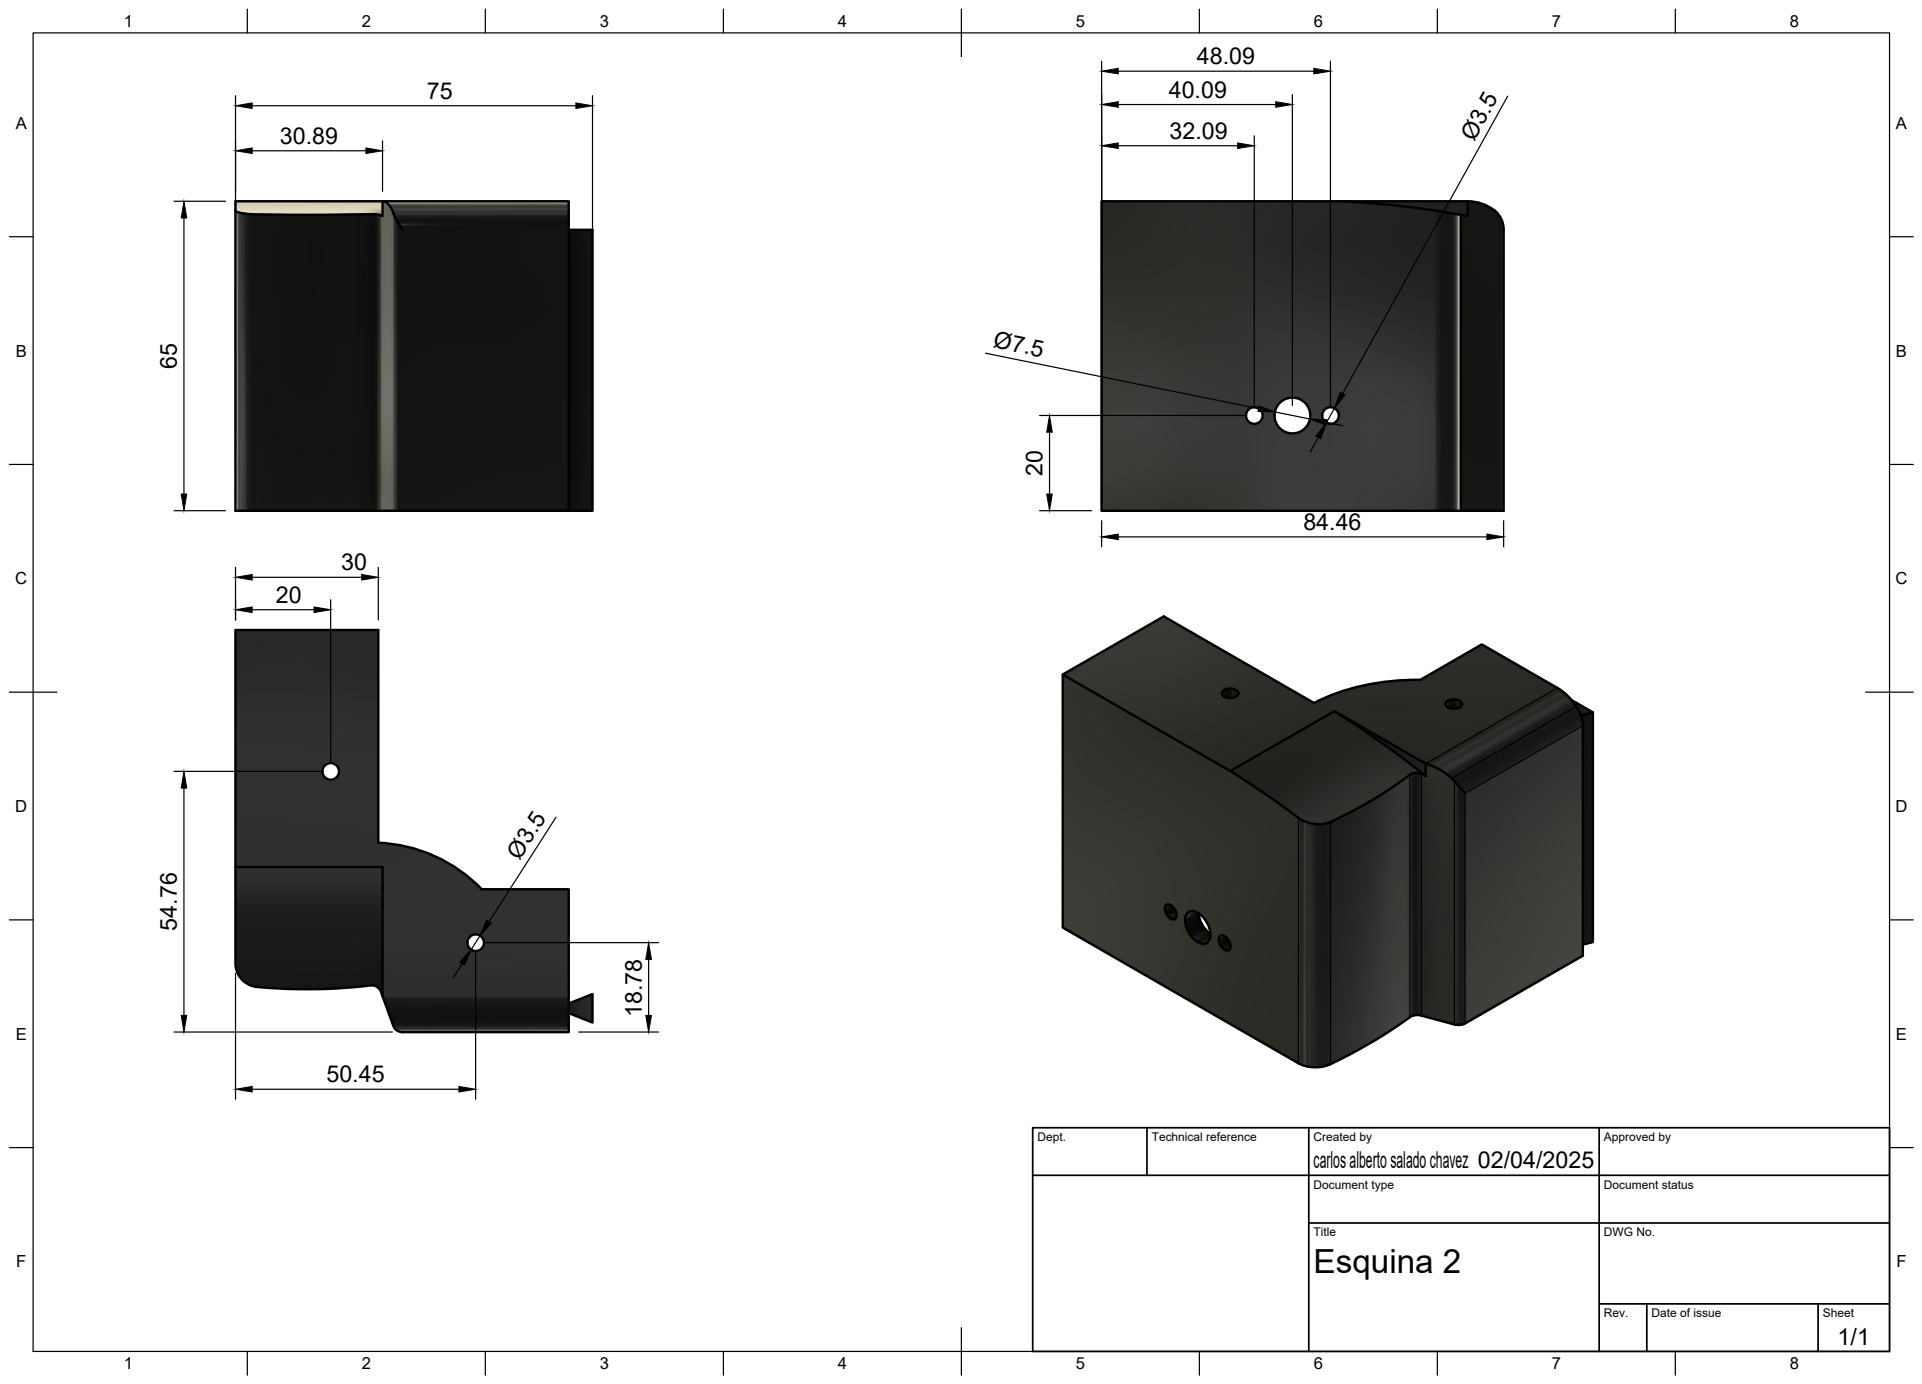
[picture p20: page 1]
Title; DWG No.; Rev.; Date of issue; Sheet; Esquina 2

Dept. | Technical reference | Created by carlos alberto salado chavez 02/04/2025 | Approved by

Document type | Document status

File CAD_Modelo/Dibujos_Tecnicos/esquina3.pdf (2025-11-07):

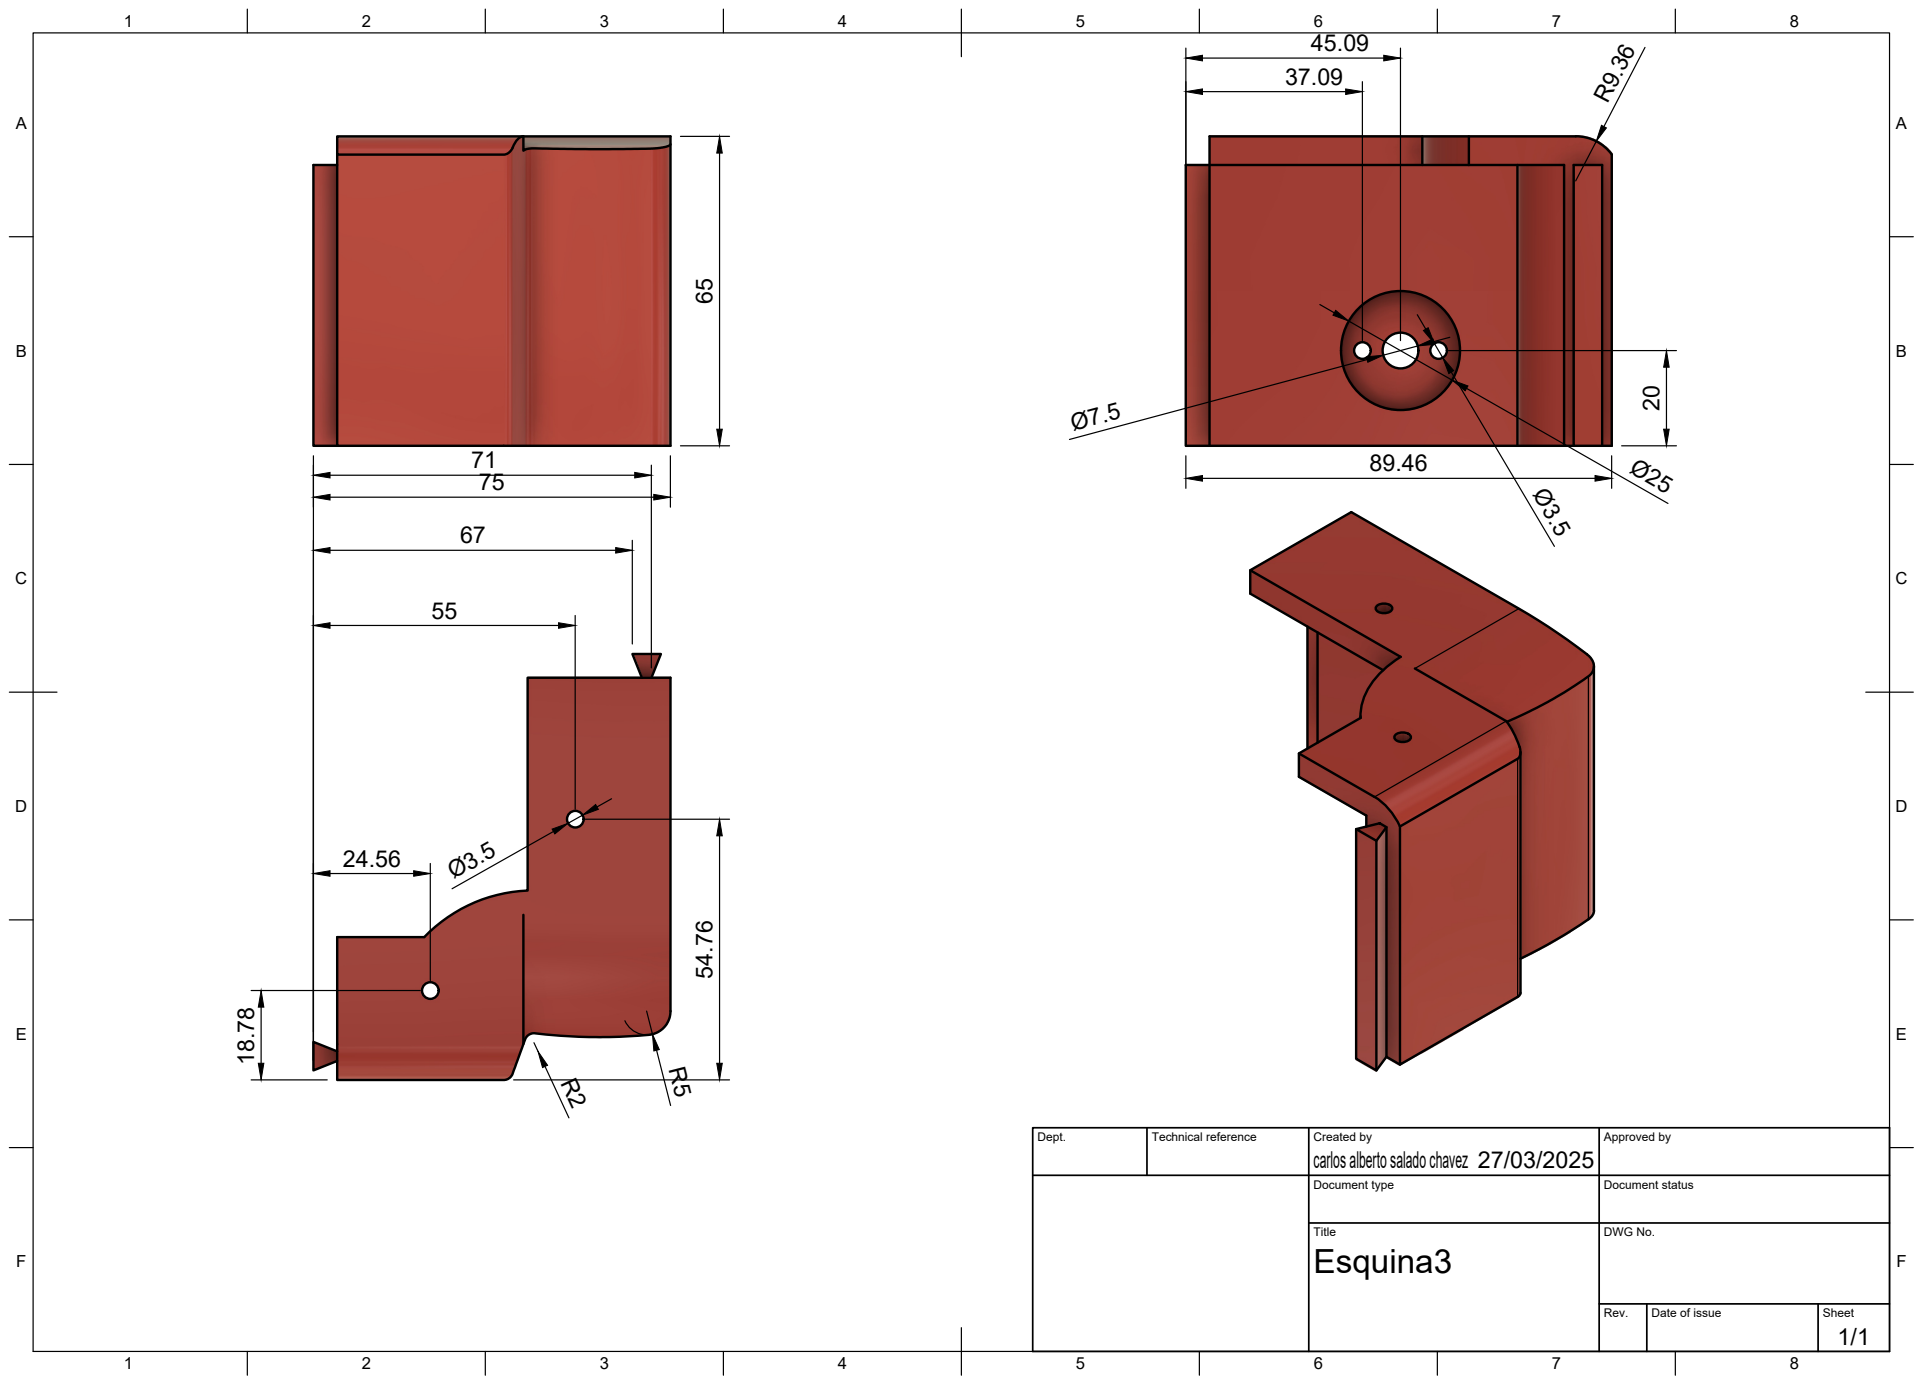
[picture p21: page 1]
Title; DWG No.; Rev.; Date of issue; Sheet

Dept. | Technical reference | Created by carlos alberto salado chavez 27/03/2025 | Approved by

Document type | Document status

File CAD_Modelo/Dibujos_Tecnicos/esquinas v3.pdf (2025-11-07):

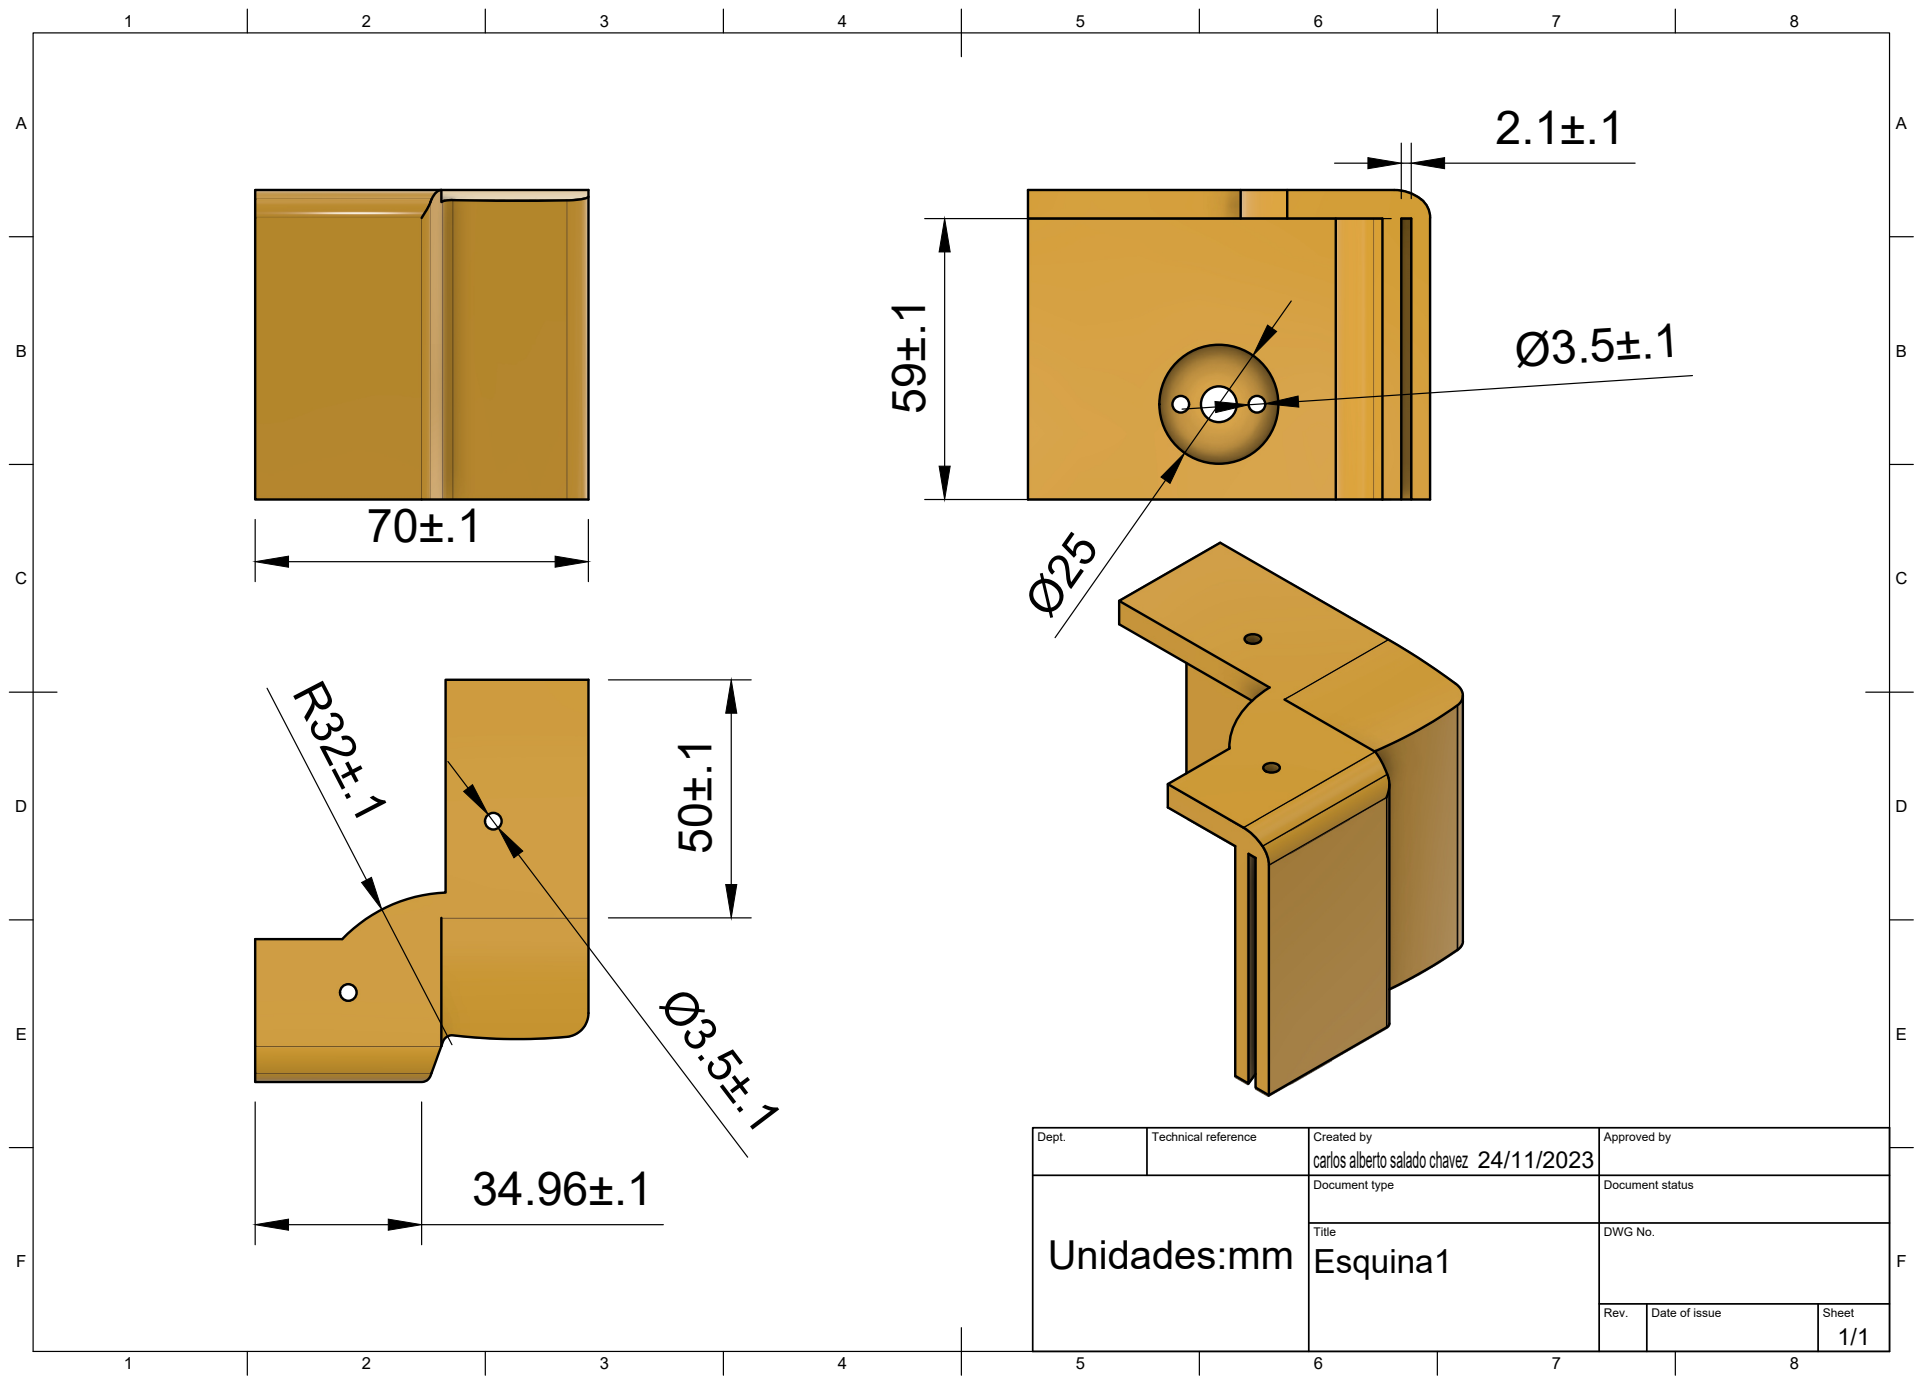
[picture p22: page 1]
Title; DWG No.; Rev.; Date of issue; Sheet

Dept. | Technical reference | Created by carlos alberto salado chavez 24/11/2023 | Approved by

Document type | Document status

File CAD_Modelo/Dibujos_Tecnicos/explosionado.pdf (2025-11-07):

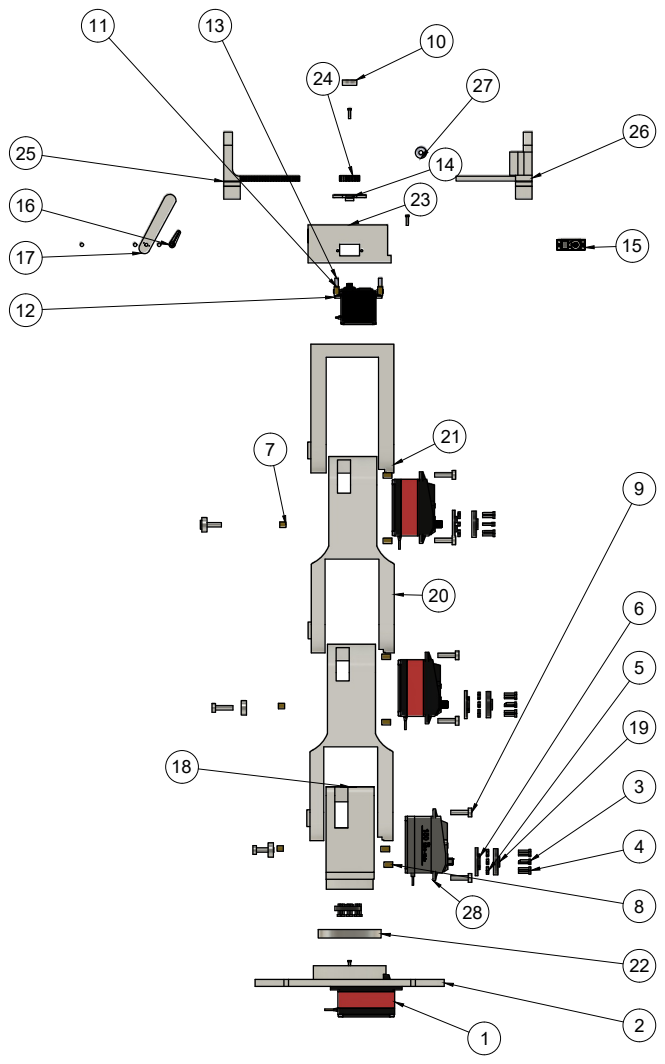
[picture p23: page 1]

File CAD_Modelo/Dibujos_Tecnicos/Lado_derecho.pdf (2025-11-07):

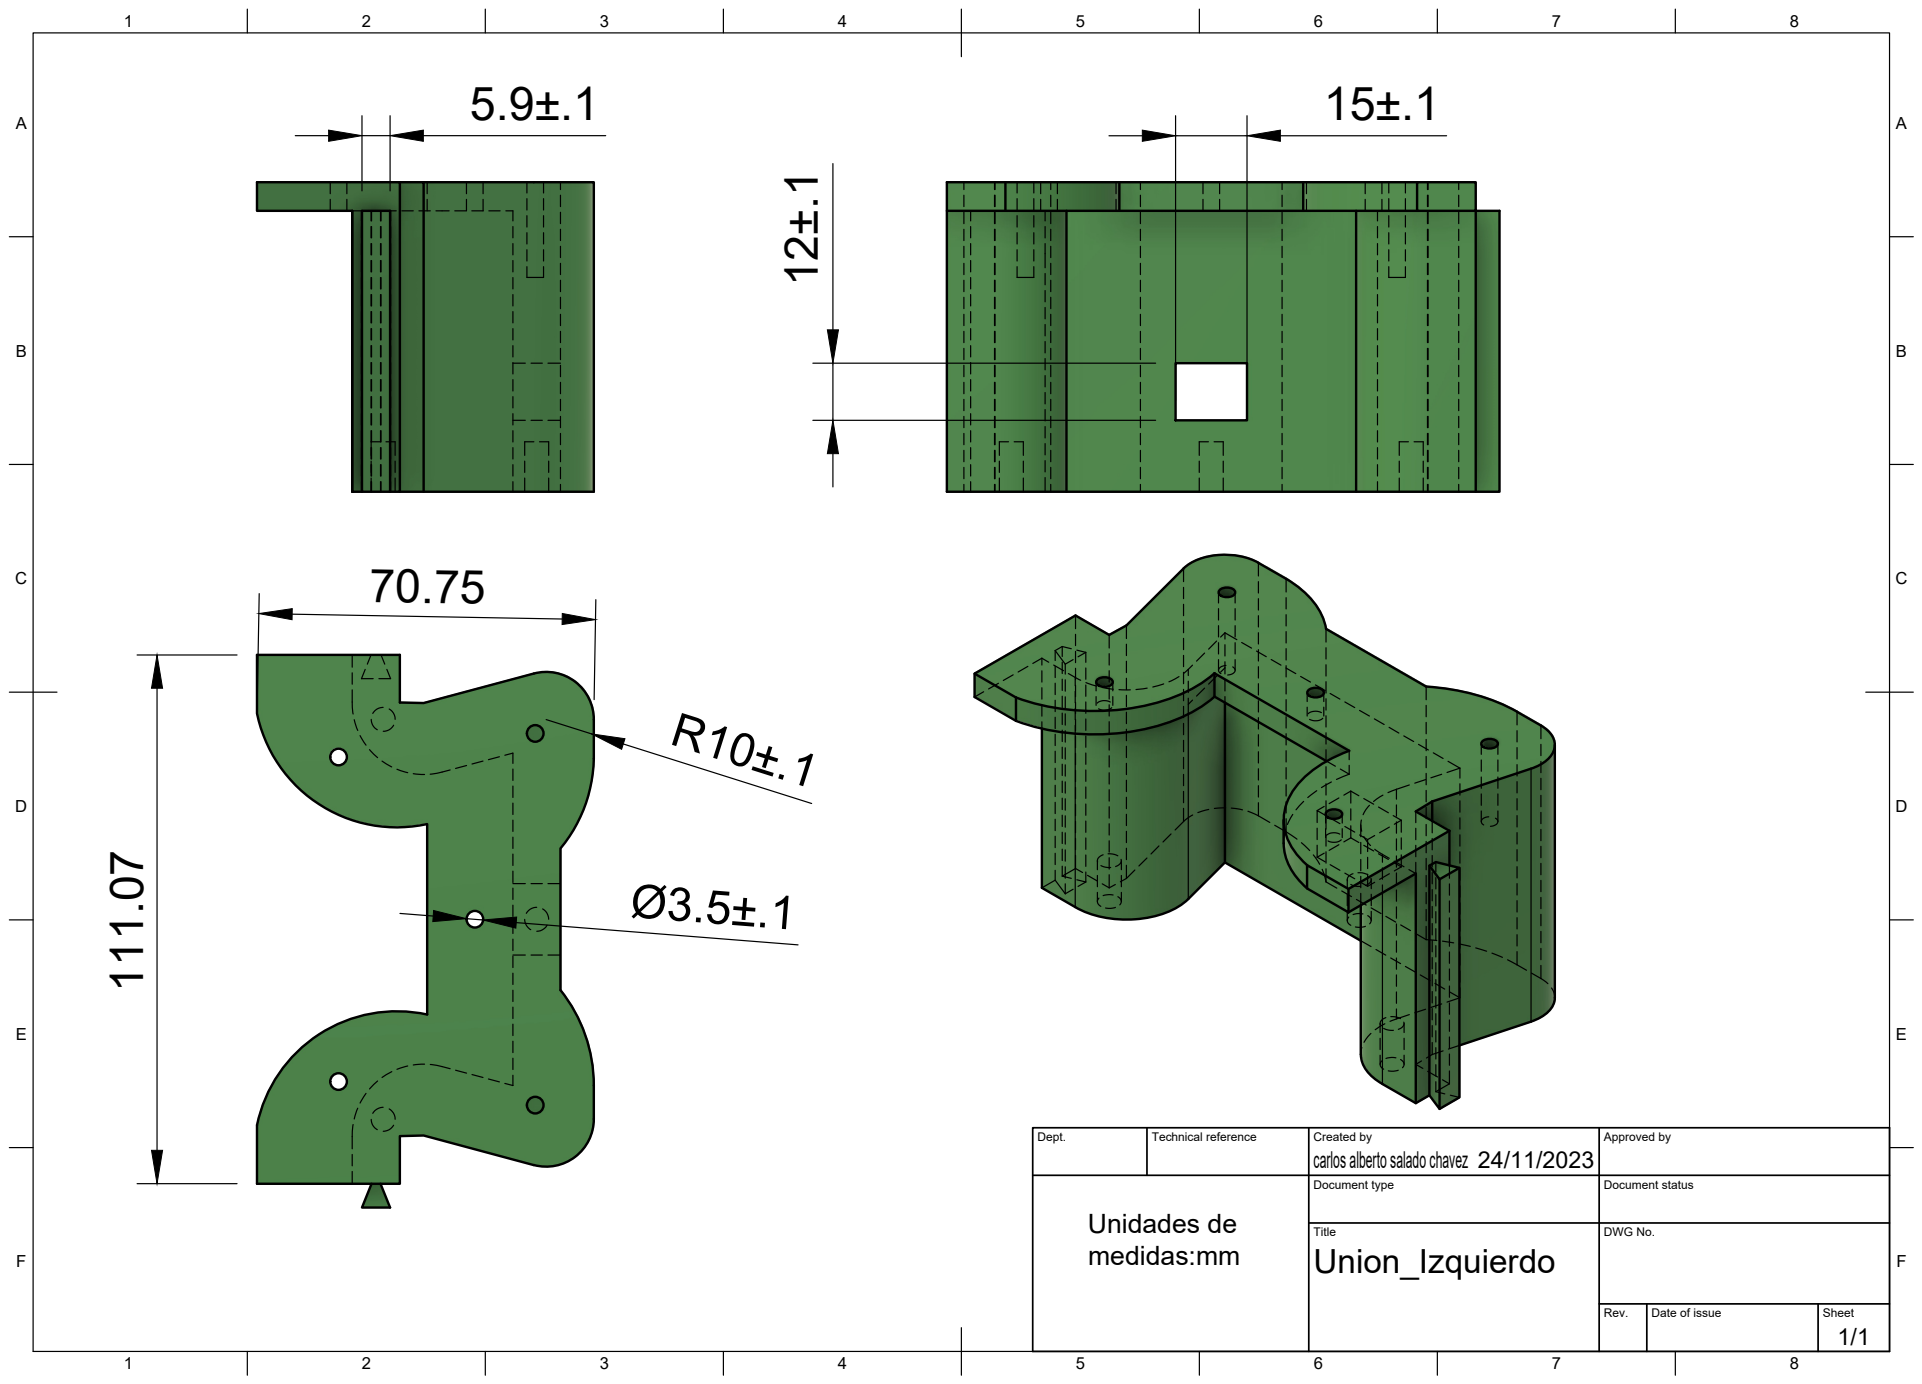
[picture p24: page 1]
Title; DWG No.; Rev.; Date of issue; Sheet; Unidades de

Dept. | Technical reference | Created by carlos alberto salado chavez 24/11/2023 | Approved by

Document type | Document status

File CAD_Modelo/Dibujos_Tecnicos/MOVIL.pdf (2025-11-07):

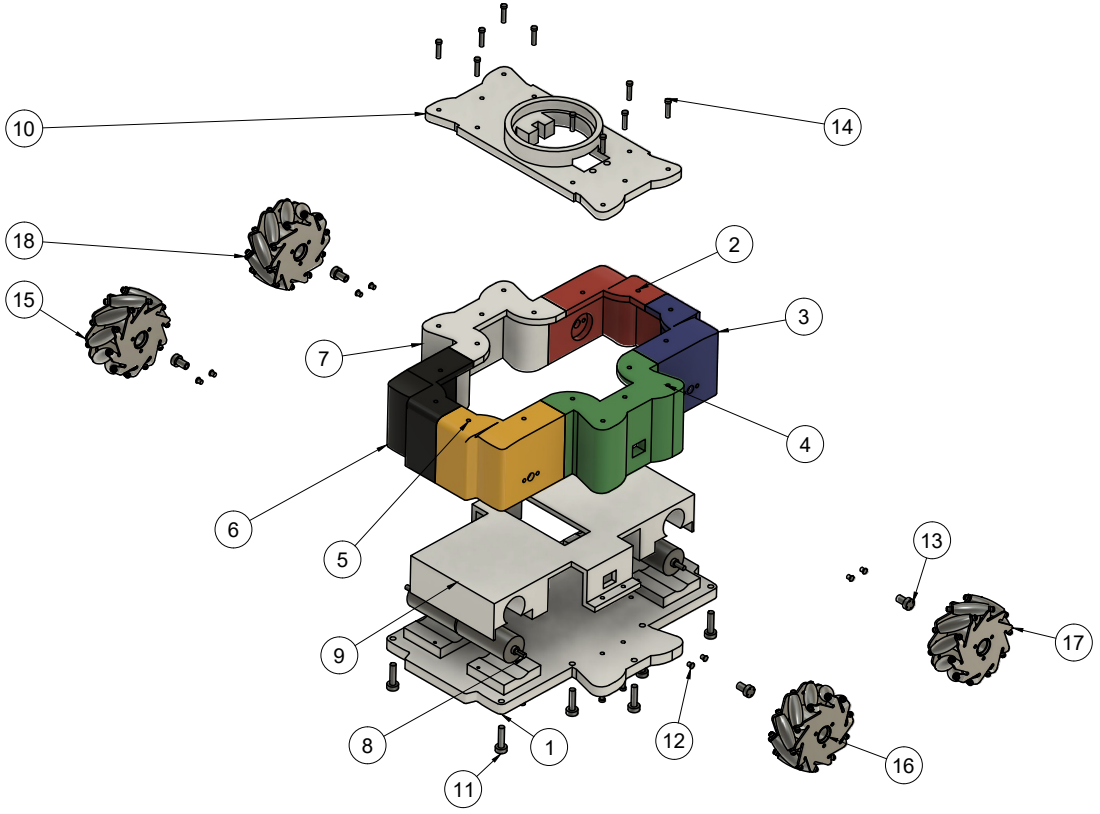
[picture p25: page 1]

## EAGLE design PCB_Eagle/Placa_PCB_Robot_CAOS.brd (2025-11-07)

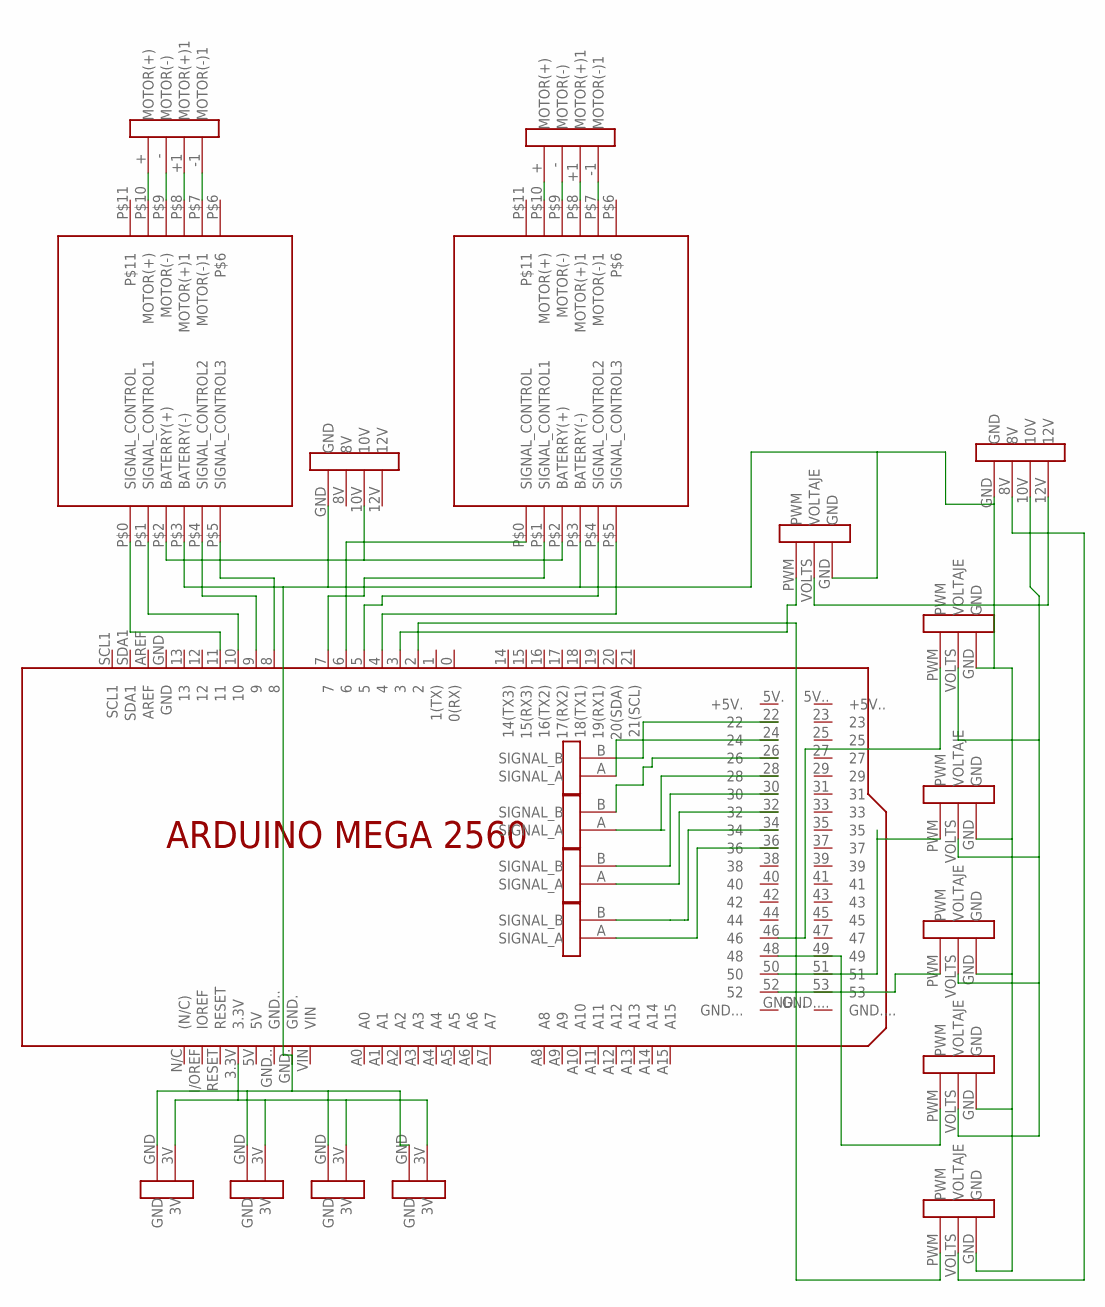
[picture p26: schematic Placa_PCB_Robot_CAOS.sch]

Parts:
INTENTO1, INTENTO2: DRV8833DRV8833; DRV8833
PCB1: ARDUINO_MEGA2560
U$1, U$2: MOTOR_CD
U$3, U$10: BATTERY
U$4, U$5, U$6, U$7, U$8, U$9: SERVO_MOTORES; SERVO_MOTOR
U$11, U$12, U$13, U$14: ENCODER_VOLTAJE
U$15, U$16, U$17, U$18: SIGNAL_ENCODER2; SIGNAL_ENCODER

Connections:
GND: INTENTO1.P$3 (BATERRY(-)), INTENTO2.P$3 (BATERRY(-)), PCB1.GND., U$3.GND, U$4.GND, U$5.GND, U$6.GND, U$7.GND, U$8.GND, U$9.GND, U$10.GND, U$11.GND, U$12.GND, U$13.GND, U$14.GND
unnamed: INTENTO1.P$10 (MOTOR(+)), U$1.+ (MOTOR(+))
unnamed: INTENTO1.P$9 (MOTOR(-)), U$1.- (MOTOR(-))
unnamed: INTENTO1.P$8 (MOTOR(+)1), U$1.+1 (MOTOR(+)1)
unnamed: U$9.VOLTS (VOLTAJE), U$10.8V
unnamed: INTENTO1.P$7 (MOTOR(-)1), U$1.-1 (MOTOR(-)1)
unnamed: INTENTO1.P$0 (SIGNAL_CONTROL), PCB1.11
unnamed: INTENTO1.P$1 (SIGNAL_CONTROL1), PCB1.10
unnamed: INTENTO2.P$10 (MOTOR(+)), U$2.+ (MOTOR(+))
unnamed: INTENTO1.P$4 (SIGNAL_CONTROL2), PCB1.9
unnamed: INTENTO1.P$5 (SIGNAL_CONTROL3), PCB1.8
unnamed: INTENTO2.P$0 (SIGNAL_CONTROL), PCB1.6
unnamed: PCB1.24, U$15.A (SIGNAL_A)
unnamed: INTENTO2.P$4 (SIGNAL_CONTROL2), PCB1.5
unnamed: INTENTO2.P$5 (SIGNAL_CONTROL3), PCB1.4
unnamed: INTENTO2.P$9 (MOTOR(-)), U$2.- (MOTOR(-))
unnamed: INTENTO2.P$8 (MOTOR(+)1), U$2.+1 (MOTOR(+)1)
unnamed: INTENTO2.P$7 (MOTOR(-)1), U$2.-1 (MOTOR(-)1)
unnamed: INTENTO1.P$2 (BATERRY(+)), INTENTO2.P$2 (BATERRY(+)), U$3.10V
unnamed: PCB1.3, U$4.PWM
unnamed: U$4.VOLTS (VOLTAJE), U$10.12V
unnamed: PCB1.50, U$6.PWM
unnamed: PCB1.52, U$7.PWM
unnamed: PCB1.48, U$8.PWM
unnamed: INTENTO2.P$1 (SIGNAL_CONTROL1), PCB1.7
unnamed: PCB1.46, U$5.PWM
unnamed: U$5.VOLTS (VOLTAJE), U$6.VOLTS (VOLTAJE), U$7.VOLTS (VOLTAJE), U$8.VOLTS (VOLTAJE), U$10.10V
unnamed: PCB1.3.3V, U$11.3V, U$12.3V, U$13.3V, U$14.3V
unnamed: PCB1.22, U$15.B (SIGNAL_B)
unnamed: PCB1.26, U$16.B (SIGNAL_B)
unnamed: PCB1.34, U$18.B (SIGNAL_B)
unnamed: PCB1.30, U$17.B (SIGNAL_B)
unnamed: PCB1.32, U$17.A (SIGNAL_A)
unnamed: PCB1.36, U$18.A (SIGNAL_A)
unnamed: PCB1.2, U$9.PWM
unnamed: PCB1.28, U$16.A (SIGNAL_A)

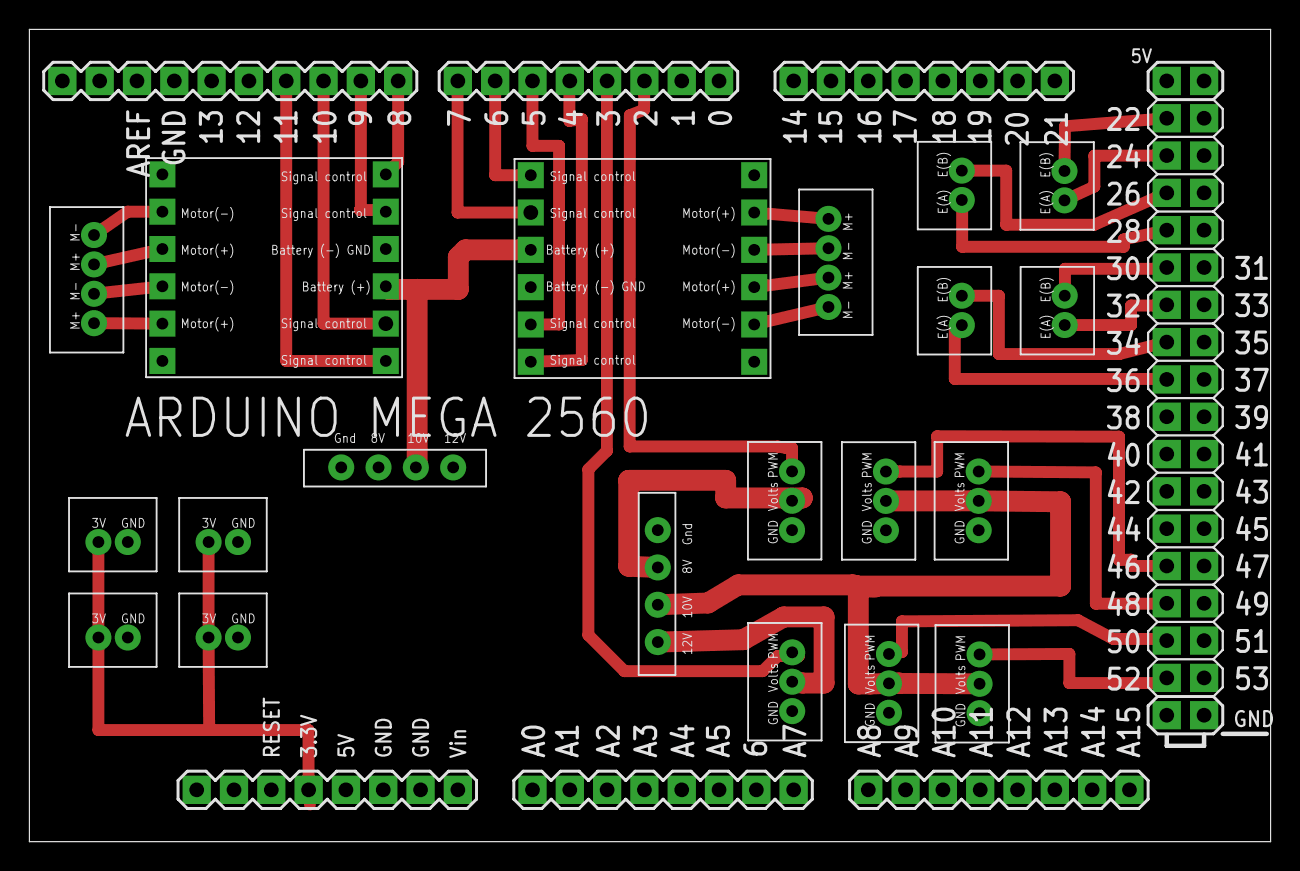
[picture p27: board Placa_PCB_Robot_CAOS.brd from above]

Board: 2 copper layers, 84.5 x 55.3 mm, 21 parts (0 on the bottom side), 36 nets.

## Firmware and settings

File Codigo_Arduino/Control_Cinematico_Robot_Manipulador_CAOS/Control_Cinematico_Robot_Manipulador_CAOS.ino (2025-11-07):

/**
 * =================================================================================
 * PROYECTO DE TESIS: "Diseño, construcción y control de un manipulador móvil"
 * AUTOR: Carlos Alberto Salado Chávez
 * INSTITUCIÓN: Universidad Tecnológica de la Mixteca (UTM)
 * FECHA: 2024-2025
 *
 * DESCRIPCIÓN:
 * Este código implementa el control cinemático combinado para un robot móvil
 * omnidireccional (base con 4 ruedas Mecanum) y un brazo manipulador serial
 * de 5 grados de libertad (GDL).
 *
 * El sistema ejecuta un único bucle de control que coordina ambos subsistemas:
 * 1.  BASE MÓVIL: Utiliza odometría y un control cinemático (P) para mover la
 * plataforma a una posición que "ayude" al brazo.
 * 2.  MANIPULADOR: Utiliza cinemática inversa (basada en el método geométrico
 * y desacoplamiento) para posicionar el efector final en el objetivo global.
 *
 * El control combinado se logra al definir el objetivo de la base no como el
 * objetivo final, sino como (Objetivo_Final - Extensión_del_Brazo).
 *
 * Basado en los modelos del Capítulo 4 de la tesis.
 *
 * =================================================================================
 * --- REFERENCIAS DE LA TESIS EN EL CÓDIGO ---
 *
 * Este código implementa directamente los modelos matemáticos del Capítulo 4:
 *
 * 1.  ODOMETRÍA (Medición de la Base):
 * - `Vfm`, `Vlm`, `Wm` (en el loop) implementan la Cinemática Directa de la Base
 * (Tesis, Capítulo 2.7, Ecuaciones 2.54 - 2.56).
 *
 * 2.  CONTROL DE LA BASE (Actuación):
 * - `V1`, `V2`, `V3`, `V4` (en el loop) implementan la Cinemática Inversa de la Base
 * (Tesis, Capítulo 4.2, Ecuación 4.9).
 *
 * 3.  CONTROL COMBINADO (La "Magia"):
 * - `ux = -k * (x - (xd - x_arm))`... implementa la Ley de Control Combinado
 * (Tesis, Capítulo 4.6, Ecuación 4.62).
 * - `calcularX1m_X2m()` implementa la Cinemática Directa del Brazo (simplificada)
 * para obtener `x_arm` y `y_arm` (Tesis, Eq. 4.14, proyectada).
 *
 * 4.  CONTROL DEL MANIPULADOR (Cinemática Inversa del Brazo):
 * - `inversa_3GDL()` implementa el cálculo de `x4, y4, z4` (Eq. 4.61) y
 * el cálculo de `th1, th2, th3` (Eq. 4.55).
 * - `actualizarAngulosLocales()` transforma la orientación deseada
 * Global -> Local (Tesis, Eq. 4.67 - 4.69).
 * - `calcularTh4()` y `calcularTh5()` implementan el resto de la
 * Ecuación 4.55 para la orientación de la muñeca.
 * =================================================================================
 */


// --- LIBRERÍAS ---
// #include "PinChangeInterrupt.h" // Se intentó usar interrupciones, pero se optó por polling
#include "motorControl.h"         // Librería personalizada para el control PID de los motores DC
#include "math.h"                 // Para operaciones matemáticas (sin, cos, atan2, etc.)
#include <SoftwareSerial.h>       // Incluido pero no utilizado en este fragmento
#include <Servo.h>                // Para el control de los servomotores del brazo

// Definir constantes para evitar cálculos repetidos
#define PI_F 3.141592653589793f
#define HALF_PI_F 1.570796326794897f
#define PI 3.141592653589793

// ====================================================================
// Variables de medición y parámetros geométricos del robot
// ====================================================================

float L = 0.097;         // Distancia desde el centro del robot hasta el punto de contacto de las ruedas (m)
float b = 0.14;          // Distancia desde el centro del robot hasta el eje del motor (m)
float r = 0.04;          // Radio de las ruedas (m)
float k = 0.15;          // Ganancia del control cinemático (ajusta la respuesta del movimiento)
float diferenciaTiempo;  // Intervalo de tiempo entre mediciones, usado en la odometría (s)

// ====================================================================
//  Definición de las velocidades y orientaciones deseadas del efector final
// ====================================================================

// Posiciones deseadas (en m)
float xd = -1;       // Componente deseada en eje X
float yd = -1;       // Componente deseada en eje Y
float zd = 0.368;    // Componente deseada en eje Z

// Orientaciones deseadas (en radianes)
double thd    = -0 * 3.1416 / 4;  // Ángulo de orientación general (de la base)
double alphaD =  3.1416 / 4;      // Ángulo de inclinación (roll)
double betaD  =  0;               // Ángulo de cabeceo (pitch)
double gammaD =  0 * 3.1416 / 6;  // Ángulo de giro de la plataforma (yaw)

// --------------------------------------------------------------------
// IMPORTANTE:
// Estas variables (alphaD, betaD, gammaD) deben volver a asignarse dentro del loop(),
// ya que en el cálculo posterior (función actualizarAngulosLocales)
// los valores se transforman al sistema de referencia local del móvil.
// Si no se reestablecen en cada ciclo, el sistema acumularía la transformación
// en cada iteración, afectando la orientación deseada.
// --------------------------------------------------------------------


// ====================================================================
// Variables temporales para registro e impresión de datos
// ====================================================================

// NOTA: 'limite' pertenece a otra parte del código (control angular o restricción de movimiento)
// y no afecta directamente la impresión de datos en el monitor serial.
float limite = 1.5708f;   // 90° en radianes (variable usada en otra sección)

// Variables de almacenamiento temporal
float x = 0;              // Posición X actual o medida
float y = 0;              // Posición Y actual o medida
int imprimir = 300;       // Cantidad de muestras a imprimir o almacenar

// Arreglos para guardar valores durante el experimento o simulación
float xvalor[300];        // Arreglo para registrar la evolución de X
float yvalor[300];        // Arreglo para registrar la evolución de Y
double thvalor[300];      // Arreglo para registrar la orientación (theta)

// Arreglos adicionales (comentados) para registrar cada articulación del manipulador
// double th1valor[600];
// double th2valor[250];
// double th3valor[250];
// double th4valor[250];
// double th5valor[250];

// --------------------------------------------------------------------
// Estos vectores permiten almacenar datos durante la ejecución del programa,
// los cuales pueden imprimirse en el monitor serial o exportarse para análisis
// (por ejemplo, en MATLAB o Python).
// --------------------------------------------------------------------


// ====================================================================
// Variables para el control cinemático del robot móvil
// ====================================================================

// Variables de velocidad deseada en el marco del robot (GLOBAL)
double ux  = 0;  // Componente de velocidad en el eje X del robot
double uy  = 0;  // Componente de velocidad en el eje Y del robot
double uth = 0;  // Velocidad angular (rotacional) deseada del robot

// Variables de velocidad lineal y angular (LOCAL)
double Vf = 0;    // Velocidad de avance (frontal)
double Vl = 0;    // Velocidad lateral
double w  = 0;    // Velocidad angular (rotación alrededor del centro)

// ====================================================================
// Variables para la odometría
// ====================================================================
// Velocidades de cada rueda (calculadas por el modelo cinemático)
double V1 = 0;
double V2 = 0;
double V3 = 0;
double V4 = 0;

// Velocidades medidas (obtenidas de sensores o encoders)
double v1m = 0;
double v2m = 0;
double v3m = 0;
double v4m = 0;

// Velocidades resultantes medidas del robot
double Vfm = 0;   // Velocidad frontal medida
double Vlm = 0;   // Velocidad lateral medida
double Wm  = 0;   // Velocidad angular medida

// ====================================================================
// Variables auxiliares para cálculos intermedios
// ====================================================================
double thm = 0;        // Ángulo de orientación estimado (odometría)
double xp = 0.0;       // Posición X estimada
double yp = 0.0;       // Posición Y estimada
double delta1 = 0.0;   // Variables de corrección o diferencia temporal
double delta2 = 0.0;
double delta3 = 0.0;
double diferentTime = 0; // Diferencia de tiempo entre ciclos (s)

// --------------------------------------------------------------------
// Estas variables se utilizan en el cálculo de la cinemática directa e
// inversa del robot móvil omnidireccional, así como en la estimación de
// su posición mediante odometría. Las variables medidas (v1m–v4m) se
// comparan con las deseadas (V1–V4) para generar la acción de control.
// --------------------------------------------------------------------
// ====================================================================
// VARIABLES PARA EL CONTROL DE LOS MOTORES Y LECTURA DE ENCODERS
// ====================================================================

// --------------------------------------------------------------------
// Variables de temporización
// --------------------------------------------------------------------
// Controlan los tiempos de muestreo y actualización del PID y la lectura
// de encoders. Los tiempos se expresan en milisegundos.
unsigned long lastTime = 0;      // Último tiempo de actualización general
unsigned long sampleTime = 100;  // Periodo de muestreo del control de velocidad (PID)
unsigned long sampleTime2 = 600; // Periodo de muestreo adicional (Manipulador)
unsigned long lastTime2 = 0;
unsigned long lastTime3 = 0;
unsigned long lastTime4 = 0;
unsigned long tiempo = 0;        // Contador global o referencia de tiempo

// --------------------------------------------------------------------
// Instancias del controlador PID para cada motor
// --------------------------------------------------------------------
// Cada objeto 'motorControl' representa un lazo PID independiente asociado
// a uno de los motores del robot. Todos se inicializan con el mismo tiempo
// de muestreo definido arriba.
motorControl motor1(sampleTime);
motorControl motor2(sampleTime);
motorControl motor3(sampleTime);
motorControl motor4(sampleTime);

// --------------------------------------------------------------------
// Configuración de pines PWM y de dirección de los motores
// --------------------------------------------------------------------
// NOTA IMPORTANTE:
// La asignación de pines depende directamente de la conexión física
// entre el Arduino, el puente H DRV8833 y el conector JST de cada motor.
// Por tanto, los valores definidos a continuación deben ajustarse según
// la orientación y el cableado descrito en la página 55 de la tesis.
// --------------------------------------------------------------------

// Motor 1
const int BI1  = 8;
const int BI12 = 9;
// Motor 2
const int BI2  = 10;
const int BI22 = 11;
// Motor 3
const int BI3  = 4;
const int BI32 = 5;
// Motor 4
const int BI4  = 6;
const int BI42 = 7;
// --------------------------------------------------------------------
// Variables de salida del control
// --------------------------------------------------------------------
// Cada variable almacena el valor PWM calculado por el controlador PID
// correspondiente al motor. Estos valores (0–255) se aplican mediante
// la función analogWrite() para accionar el driver de potencia.
int outValue1 = 0;
int outValue2 = 0;
int outValue3 = 0;
int outValue4 = 0;

// --------------------------------------------------------------------
// DESCRIPCIÓN GENERAL:
// Este bloque implementa el control de bajo nivel del sistema, en el cual
// cada motor dispone de un controlador PID independiente. El lazo PID
// ajusta la velocidad medida por el encoder a la velocidad deseada que
// proviene del modelo cinemático del robot móvil omnidireccional.
// --------------------------------------------------------------------

// --------------------------------------------------------------------
// NOTA IMPORTANTE:
// Este bloque se encarga del control de bajo nivel de los actuadores,
// en el que cada motor tiene un lazo PID independiente encargado de
// ajustar su velocidad medida (por encoder) a la velocidad deseada
// proveniente del control cinemático del robot móvil.
// --------------------------------------------------------------------
// ====================================================================
// VARIABLES Y CONFIGURACIÓN DE LOS ENCODERS DE LOS MOTORES
// ====================================================================

// --------------------------------------------------------------------
// NOTA IMPORTANTE:
// La asignación de pines para los encoders depende directamente del
// conexionado físico entre el Arduino, los encoders,
// mediante los conectores JST. El orden de las señales puede variar
// según la orientación del conector y el esquema mostrado en la página 55
// de la tesis. Por tanto, los valores definidos a continuación deben
// ajustarse según la disposición real del hardware.
// --------------------------------------------------------------------

// ====================================================================
// Motor 1
// ====================================================================
const int E1  = 30;  // Entrada A del encoder del motor 1
const int E12 = 32;  // Entrada B del encoder del motor 1
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
void loop() {
  // ===============================================================
  // 🔹 0. REASIGNACIÓN DE OBJETIVO GLOBAL
  // ===============================================================
  // (Tesis, Nota Importante en Variables)
  // Re-establece las orientaciones deseadas GLOBALES en cada ciclo.
  // La función 'actualizarAngulosLocales' las modificará para
  // convertirlas en objetivos LOCALES para el brazo.
  alphaD = 3.1416 / 4; // 45°
  betaD  = 0;
  gammaD = 0;

  // ===============================================================
  // 🔹 1. LECTURA DE ESTADO (ENCODERS Y SERVOS)
  // ===============================================================
  // En cada iteración del loop principal se actualiza el estado
  // de los sensores (encoders) y los actuadores (servomotores).

  // ---------------- 🧩 Lectura de Encoders -----------------------
  // Guarda el estado anterior ('ant') y lee el estado actual ('act')
  // de los 2 pines (Canal A y Canal B) de cada encoder.
  // (digitalRead(A) << 1) | digitalRead(B) combina las lecturas
  // en un solo número de 2 bits (0-3) para la lógica de cuadratura.

  ant12 = act12;
  act12 = (digitalRead(E1) << 1) | digitalRead(E12);

  ant22 = act22;
  act22 = (digitalRead(E2) << 1) | digitalRead(E22);

  ant32 = act32;
  act32 = (digitalRead(E3) << 1) | digitalRead(E32);

  ant42 = act42;
  act42 = (digitalRead(E4) << 1) | digitalRead(E42);

  // ---------------- ⚙️ Actualización de Servos ------------------
  // Llama a la función de movimiento suave (no bloqueante).
  //
  // 💡 Nota: servo2 (hombro) usa el servo DS51150 (150 kg·cm).
  // Se le aplica un factor ×2.3 en el retardo para ajustar su
  // velocidad y adaptarla a su respuesta física real (calibración).

  updateServo(servo1, pos1, targetPos1, stepDelay,       lastUpdateServo1); // Base
  updateServo(servo2, pos2, targetPos2, stepDelay * 2.3, lastUpdateServo2); // Hombro (servo lento)
  updateServo(servo3, pos3, targetPos3, stepDelay,       lastUpdateServo3); // Codo
  updateServo(servo4, pos4, targetPos4, stepDelay,       lastUpdateServo4); // Muñeca Pitch
  updateServo(servo5, pos5, targetPos5, stepDelay,       lastUpdateServo5); // Muñeca Roll


  // ===============================================================
  // 🔹 2. DECODIFICACIÓN DE ENCODERS EN CUADRATURA
  // ===============================================================
  // Compara el estado anterior (`ant`) con el actual (`act`) para
  // incrementar o decrementar el contador de pulsos (n*2).
  // Esto mide la rotación y la dirección de cada rueda.
  // ---------------------------------------------------------------

  // === MOTOR 1 ===
  if (ant12 == 0 && act12 == 1) n12++;
  if (ant12 == 1 && act12 == 3) n12++;
  if (ant12 == 2 && act12 == 0) n12++;
  if (ant12 == 3 && act12 == 2) n12++;
  if (ant12 == 0 && act12 == 2) n12--;
  if (ant12 == 1 && act12 == 0) n12--;
  if (ant12 == 2 && act12 == 3) n12--;
  if (ant12 == 3 && act12 == 1) n12--;

  // === MOTOR 2 ===
  if (ant22 == 0 && act22 == 1) n22++;
  if (ant22 == 1 && act22 == 3) n22++;
  if (ant22 == 2 && act22 == 0) n22++;
  if (ant22 == 3 && act22 == 2) n22++;
  if (ant22 == 0 && act22 == 2) n22--;
  if (ant22 == 1 && act22 == 0) n22--;
  if (ant22 == 2 && act22 == 3) n22--;
  if (ant22 == 3 && act22 == 1) n22--;

  // === MOTOR 3 ===
  if (ant32 == 0 && act32 == 1) n32++;
  if (ant32 == 1 && act32 == 3) n32++;
  if (ant32 == 2 && act32 == 0) n32++;
  if (ant32 == 3 && act32 == 2) n32++;
  if (ant32 == 0 && act32 == 2) n32--;
  if (ant32 == 1 && act32 == 0) n32--;
  if (ant32 == 2 && act32 == 3) n32--;
  if (ant32 == 3 && act32 == 1) n32--;

  // === MOTOR 4 ===
  if (ant42 == 0 && act42 == 1) n42++;
  if (ant42 == 1 && act42 == 3) n42++;
  if (ant42 == 2 && act42 == 0) n42++;
  if (ant42 == 3 && act42 == 2) n42++;
  if (ant42 == 0 && act42 == 2) n42--;
  if (ant42 == 1 && act42 == 0) n42--;
  if (ant42 == 2 && act42 == 3) n42--;
  if (ant42 == 3 && act42 == 1) n42--;


  // ================================================================
  // 🔹 3. CICLO DE CONTROL PRINCIPAL (10 Hz)
  // ================================================================
  // Este bloque se ejecuta cada 'sampleTime' milisegundos.
  // Es el núcleo del sistema de control combinado.
  // ---------------------------------------------------------------

  if (millis() - lastTime >= sampleTime) {

    // --- 3.1 CÁLCULO DEL TIEMPO ---
    unsigned long dt_ms = millis() - lastTime;
    float dt_s = dt_ms / 1000.0;  // Tiempo transcurrido (s)

    // --- 3.2 ODOMETRÍA (VELOCIDAD DE RUEDAS) ---
    // Convierte los ticks del encoder (n*2) en velocidad angular (rad/s)
    w1 = constValue2 * n12 / dt_ms;
    w2 = constValue1 * n22 / dt_ms;
    w3 = constValue1 * n32 / dt_ms;
    w4 = constValue1 * n42 / dt_ms;

    // Reinicia los contadores para el siguiente ciclo
    n12 = n22 = n32 = n42 = 0;

    // Velocidad tangencial (m/s)
    v1m = w1 * r;
    v2m = w2 * r;
    v3m = w3 * r;
    v4m = w4 * r;

    // --- 3.3 CINEMÁTICA DIRECTA (BASE MÓVIL) ---
    // (Tesis Eq. 2.54-2.56)
    // Calcula la velocidad local (Frontal, Lateral, Angular) de la base
    // a partir de las 4 velocidades de las ruedas medidas.
    Vfm = (v1m + v2m + v3m + v4m) / 4.0;            // Velocidad frontal
    Vlm = (-v1m + v2m + v3m - v4m) / 4.0;           // Velocidad lateral
    Wm  = (-v1m + v2m - v3m + v4m) / (4.0 * (L + b)); // Velocidad angular (rad/s)

    // --- 3.4 ESTIMACIÓN DE POSICIÓN (ODOMETRÍA INTEGRADA) ---
    
    // Calcula la extensión actual del brazo (x_arm, y_arm) en el marco global.
    // Esta función usa (th1, th2, th3, th4) y (thm) para la cinemática directa del brazo.
    calcularX1m_X2m();

    // Integra la velocidad angular (Wm) para obtener la orientación (thm)
       delta1 = (Wm * (millis() - lastTime)) / 1000;
        thm += delta1;
    // Proyecta las velocidades locales (Vfm, Vlm) al marco global usando 'thm'
    // (Tesis Eq. 4.1)
    xp = Vfm * cos(thm) - Vlm * sin(thm); // Velocidad global en X
    yp = Vfm * sin(thm) + Vlm * cos(thm); // Velocidad global en Y

    // Integra las velocidades globales para obtener la posición (x, y)
        delta2 = (xp * (millis() - lastTime)) / 1000;
        x += delta2;
        delta3 = (yp * (millis() - lastTime)) / 1000;
        y += delta3;

    // --- 3.5 REGISTRO DE DATOS (DEPURACIÓN) ---
    // Guarda el estado actual en arreglos para análisis posterior
    xvalor[var]  = x;
    yvalor[var]  = y;
    thvalor[var] = thm;

    /*
    if (var == imprimir) {
        // Sección opcional para imprimir valores por Serial
    }
    */

    // --- 3.6 LEY DE CONTROL CINEMÁTICO (CONTROL COMBINADO) ---
    // (Tesis Eq. 4.62)
    // Calcula el error. Esta es la clave del CONTROL COMBINADO.
    // El objetivo de la base no es (xd, yd), sino (xd - x_arm, yd - y_arm).
    // La base se mueve para "ayudar" al brazo a alcanzar el objetivo final.
    ux  = -k * (x - (xd - x_arm)); // Error de posición en X -> Velocidad deseada X
    uy  = -k * (y - (yd - y_arm)); // Error de posición en Y -> Velocidad deseada Y
    uth = -k * (thm - thd);      // Error de orientación -> Velocidad angular deseada

    // Ajuste de ganancia (Gain Scheduling):
    // Reduce la ganancia 'k' cuando está cerca del objetivo para
    // disminuir la velocidad y evitar oscilaciones (frenado suave).
    if (abs(x - (xd - x_arm)) < 0.15 && abs(y - (yd - y_arm)) < 0.25) {
      k = 0.3;
    }

    // Transformación de velocidades globales deseadas (ux, uy) al marco local (Vf, Vl)
    // (Tesis Eq. 4.8)
    Vf = ux * cos(thm) + uy * sin(thm);
    Vl = -ux * sin(thm) + uy * cos(thm);
    w  = uth;

    // --- 3.7 CINEMÁTICA INVERSA (BASE MÓVIL) ---
    // (Tesis Eq. 4.9)
    // Convierte las velocidades locales deseadas (Vf, Vl, w) en las
    // velocidades tangenciales deseadas para cada una de las 4 ruedas (V1-V4).
    V1 = (Vf - Vl - (L + b) * w);
    V2 = (Vf + Vl + (L + b) * w);
    V3 = (Vf + Vl - (L + b) * w);
    V4 = (Vf - Vl + (L + b) * w);

    // Convierte de m/s a rad/s (velocidad angular de la rueda)
    V1 /= r; V2 /= r; V3 /= r; V4 /= r;

    // --- 3.8 SATURACIÓN (LÍMITES DE VELOCIDAD) ---
    // Limita la velocidad deseada (V1-V4) a los máximos físicos
    // (pvMax*) que los motores pueden alcanzar.
    V1 = constrain(V1, -pvMax1, pvMax1);
    V2 = constrain(V2, -pvMax2, pvMax2);
    V3 = constrain(V3, -7, pvMax3);  // Límite especial calibrado
    V4 = constrain(V4, -pvMax4, pvMax4);
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

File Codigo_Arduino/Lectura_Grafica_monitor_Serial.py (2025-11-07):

import serial
import csv
import os

# Abrir puerto serial
ser = serial.Serial('COM5', 9600, timeout=1)

# Archivo CSV en la misma carpeta
ruta_csv = os.path.join(os.getcwd(), "datos.csv")

datos = []  # Lista temporal para almacenar 210 datos
columnas = []  # Lista de columnas completas

print("Esperando datos...\n")

while True:
    try:
        if ser.in_waiting > 0:
            linea = ser.readline().decode('utf-8').strip()
            if linea:
                try:
                    valor = float(linea.split('=')[1])
                    print("Valor recibido:", valor)
                    datos.append(valor)

                    # Cuando lleguen 210 datos, pasarlos a una columna
                    if len(datos) == 600:
                        columnas.append(datos)
                        datos = []  # Reiniciar para la siguiente columna

                        # Guardar en CSV transpuesto (columnas)
                        max_filas = max(len(col) for col in columnas)
                        with open(ruta_csv, mode='w', newline='') as archivo_csv:
                            escritor = csv.writer(archivo_csv)
                            for i in range(max_filas):
                                fila = []
                                for col in columnas:
                                    if i < len(col):
                                        fila.append(col[i])
                                    else:
                                        fila.append('')
                                escritor.writerow(fila)
                            archivo_csv.flush()
                        print(f"Se guardaron {len(columnas)} columna(s) de 210 datos cada una.")

                except:
                    print("Dato no numérico:", linea)

    except KeyboardInterrupt:
        print("Lectura interrumpida.")
        break
    except Exception as e:
        print("Error:", e)
